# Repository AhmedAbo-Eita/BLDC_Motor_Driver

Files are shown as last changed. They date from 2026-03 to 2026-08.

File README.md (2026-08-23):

# 3-Phase BLDC & PMSM Motor Controller (ESC)







A high-performance, compact 3-phase Field-Oriented Control (FOC) Brushless DC (BLDC) and Permanent Magnet Synchronous Motor (PMSM) driver designed for robotics, e-mobility, actuators, and industrial automation.

This repository contains the complete end-to-end design stack:
* **Hardware:** Production-ready 8-layer PCB design (KiCad 10), complete multi-sheet schematics, BOM, Gerbers, assembly files, and LTspice circuit simulations.
* **Firmware:** Embedded C project for STM32G431 utilizing hardware CORDIC/FMAC acceleration, advanced motor timers, ADCs, and industrial communication stacks.
* **Control Modeling:** MATLAB/Simulink system-level simulation models for FOC algorithm development, parameter tuning, and sensorless state estimation.

---

## Hardware Preview (BLDC_MC_V1.0)

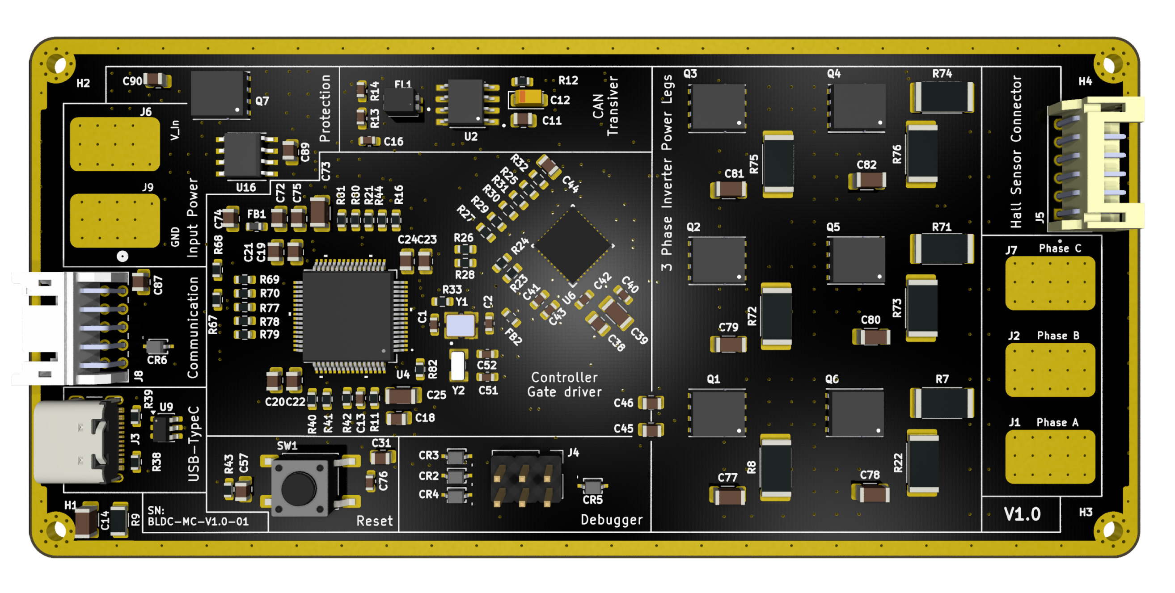
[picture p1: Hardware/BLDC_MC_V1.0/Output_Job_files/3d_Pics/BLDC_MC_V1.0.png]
BLDC_MC_V1.0 Top View


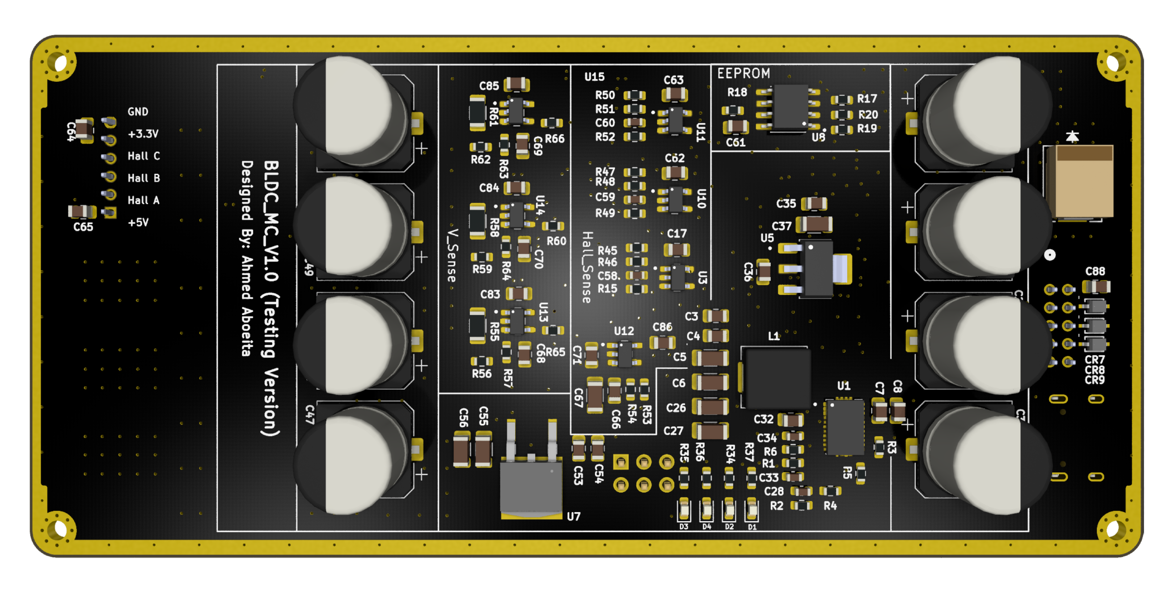
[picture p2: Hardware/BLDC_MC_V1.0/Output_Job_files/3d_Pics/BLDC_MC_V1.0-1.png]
BLDC_MC_V1.0 Bottom View


---

## Hardware V1.0 Summary & Highlight

### Key Technical Specifications

| Parameter | Specification | Details / Subsystem |
| :--- | :--- | :--- |
| **Operating Voltage ($V_{BUS}$)** | **24 V – 60 V** (60 V max) | Active reverse-polarity protection + TVS transient clamping |
| **Rated Phase Current** | **30 A continuous / peak** | Low $R_{DS(on)}$ MOSFETs + 8-layer high-copper thermal dissipation |
| **PWM Switching Frequency** | Up to **100 kHz** | Driven by STM32 advanced motor control timers |
| **Microcontroller** | **STM32G431RBT6** | 170 MHz ARM Cortex-M4, FPU, CORDIC & FMAC co-processors |
| **Gate Driver IC** | **TI DRV8353HRTAR** | Smart gate driver ($1.4\,\text{A}$ source / $700\,\text{mA}$ sink), $V_{DS}$ monitor |
| **Power Inverter Stage** | 6x **Infineon BSC027N10NS5** | 100 V, $2.7\,\text{m}\Omega$, SuperSO-8 (TDSON-8) with RC snubbers |
| **Current Sensing** | 3x **$1\,\text{m}\Omega$ Shunts** | Low-side 3-shunt sensing with shielded 4-wire Kelvin routing |
| **Voltage / BEMF Sensing** | 3-Phase Resistor Dividers | Buffered with active $+1.65\,\text{V}$ virtual ground (TLV9061) |
| **Position Feedback** | Hall Sensors + Encoders | Buffered 5 V to 3.3 V Hall inputs with RC filtering |
| **Onboard Memory** | **256 Kbit SPI EEPROM** | Microchip 25LC256 for calibration parameters & PID profiles |
| **Connectivity** | **CAN / CAN-FD, USB-C, UART, I2C** | TCAN334DR transceiver + USBLC6-2SC6 ESD protection |
| **Auxiliary Power Supplies** | **12 V / 5 V / 3.3 V** | LM74700 Ideal Diode, 12V Buck, NCV4274 (5V), LDL1117 (3.3V) |
| **PCB Form Factor** | **8-Layer High-TG180 FR4** | 2 oz outer copper, controlled impedance, 1.65 mm thickness |

---

## Repository Structure

```text
BLDC_Motor_Driver/
├── Control_Modeling/       # MATLAB & Simulink models for FOC algorithm simulation
├── Firmware/               # STM32G431 embedded C firmware (STM32CubeIDE)
└── Hardware/               # Hardware designs, simulations & manufacturing files
    ├── BLDC_MC_V1.0/       # KiCad design, schematics, BOM, Gerbers & 3D renders
    └── Simulation/         # LTspice circuit simulations
```

---

## Project Development Status

| Subsystem | Milestone | Status | Details |
| :--- | :--- | :---: | :--- |
| **Hardware (V1.0)** | Schematic & PCB Layout | **Completed** | 10 modular schematic sheets, DRC passed, 8-layer stackup |
| **Hardware (V1.0)** | Fabrication Files (Gerbers/BOM/PnP) | **Completed** | Full manufacturing package generated in [`Output_Job_files`](Hardware/BLDC_MC_V1.0/Output_Job_files/) |
| **Hardware (V1.0)** | Circuit Simulations | **Completed** | Hall sensor conditioning and active virtual-ground voltage sensor validated |
| **Firmware** | BSP & Low-level Drivers | **In Progress** | STM32G431 peripheral configuration (PWM timers, ADCs, SPI, CAN, UART) |
| **Firmware** | FOC & Commutation Algorithms | **In Progress** | Space Vector PWM (SVPWM), Park/Clarke transforms, current control loop |
| **Control Modeling** | System-Level Simulation | **In Progress** | Simulink motor and inverter models for tuning PI loops & observing dynamics |

---

## Detailed Hardware Documentation & Deliverables

For full details on the schematic sheet breakdown, connector pinouts, controlled impedance layout rules, and fabrication deliverables, refer to:
* **[Hardware V1.0 Comprehensive Documentation](Hardware/BLDC_MC_V1.0/Readme.md)**
* **[Hardware Versions & Overview](Hardware/Readme.md)**
* **[Schematic PDF](Hardware/BLDC_MC_V1.0/Output_Job_files/Board_SCH/BLDC_MC_V1.0.pdf)**
* **[Bill of Materials (BOM)](Hardware/BLDC_MC_V1.0/Output_Job_files/BOM_File/BLDC_MC_V1.0_PDF.pdf)**
* **[Fabrication Gerber Files](Hardware/BLDC_MC_V1.0/Output_Job_files/Fabrication_Files/)**

---

## Author & Project Information

* **Lead Hardware Engineer:** Ahmed Aboeita
* **Design Tools:** KiCad 10.0.5, STM32CubeIDE, MATLAB / Simulink, LTspice

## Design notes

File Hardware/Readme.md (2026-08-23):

# BLDC Motor Driver Hardware

Hardware designs for the BLDC motor driver family. Each hardware version contains complete KiCad 10 design files, schematic hierarchy, stackup definitions, circuit simulations, and production fabrication outputs.

---

## Hardware Versions

### V1.0 - 3-Phase BLDC/PMSM Motor Controller (ESC)
**Status:** **Completed & Fabrication Ready** (Rev 1.0, 2026-08-17)

BLDC_MC_V1.0 Top View

BLDC_MC_V1.0 Bottom View

A high-performance 3-phase motor controller designed for robotics, e-mobility, and industrial automation, tailored for sensored and sensorless Field-Oriented Control (FOC).

#### Technical Specifications Summary

| Specification | Value | Notes |
| :--- | :--- | :--- |
| **DC Bus Voltage** | **24 V – 60 V** (60 V max) | Bulk capacitor bank + TVS transient surge clamping |
| **Maximum Phase Current** | **30 A maximum** | Low $R_{DS(on)}$ MOSFETs + 8-layer thermal distribution |
| **PWM Switching Frequency** | Up to **100 kHz** | High-speed gate drive + STM32 advanced motor timer |
| **Main Processing Unit** | **STM32G431RBT6** | 170 MHz ARM Cortex-M4 with hardware CORDIC / FMAC |
| **Gate Driver IC** | **TI DRV8353HRTAR** | Smart Gate Drive ($1.4\,\text{A}$ source / $700\,\text{mA}$ sink) + $V_{DS}$ monitor |
| **Power Stage** | 6x **Infineon BSC027N10NS5** | 100 V, $2.7\,\text{m}\Omega$, SuperSO-8 with RC snubbers |
| **Current Sensing** | 3x **$1\,\text{m}\Omega$ Shunts** | Low-side 3-shunt sensing with Kelvin differential routing |
| **Phase Voltage Sensing** | 3-Phase Divider + Buffer | Active $+1.65\,\text{V}$ virtual ground (TLV9061) for BEMF / FOC |
| **Sensored Feedback** | 3-Channel Hall Interface | Buffered 5 V to 3.3 V with RC filtering |
| **PCB Stackup** | **8-Layer High-TG180 FR4** | 2 oz outer copper, controlled impedance (50 $\Omega$ / 100 $\Omega$) |
| **Auxiliary Rails** | **12 V, 5 V, 3.3 V** | LM74700 Ideal Diode, 12V Buck, NCV4274 (5V), LDL1117 (3.3V) |
| **Communication** | **CAN/CAN-FD, USB-C, UART, I2C** | TCAN334DR transceiver + USBLC6-2SC6 ESD protection |

#### Deliverables & Manufacturing Files

* **[Comprehensive Technical Documentation](BLDC_MC_V1.0/Readme.md)**
* **[Schematic PDF](BLDC_MC_V1.0/Output_Job_files/Board_SCH/BLDC_MC_V1.0.pdf)**
* **[Bill of Materials (BOM PDF)](BLDC_MC_V1.0/Output_Job_files/BOM_File/BLDC_MC_V1.0_PDF.pdf)** | **[BOM CSV](BLDC_MC_V1.0/Output_Job_files/BOM_File/BLDC_MC_V1.0_CSV.csv)**
* **[Fabrication Files (Gerbers & Drill)](BLDC_MC_V1.0/Output_Job_files/Fabrication_Files/)**
* **[Pick & Place Centroid Data (PnP)](BLDC_MC_V1.0/Output_Job_files/PnP_File/BLDC_MC_V1.0-all-pos.csv)**
* **[LTspice Circuit Simulations](Simulation/)**

---

## Directory Structure

```text
Hardware/
├── BLDC_MC_V1.0/               # V1.0 KiCad design files, schematics, and stackup
│   ├── Output_Job_files/       # Fabrication Gerbers, BOM, PnP, and 3D renders
│   └── Readme.md               # Detailed technical documentation & pinouts
└── Simulation/                 # LTspice circuit simulation models & testbenches
```

---

## Project Information

* **Lead Hardware Engineer:** Ahmed Aboeita
* **Design Tool:** KiCad EDA v10.0.5
* **Revision:** Rev 1.0 (Released: 2026-08-17)

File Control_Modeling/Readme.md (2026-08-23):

# BLDC & PMSM Control Modeling & Simulation

System-level simulation models and control design scripts built in MATLAB and Simulink for the BLDC motor driver family.

---

## Directory Structure

```text
Control_Modeling/
├── Functions/          # Mathematical transformations and helper functions
├── Models/             # Simulink system-level models (.slx)
│   └── BLDC_System_Level.slx # Complete 3-phase inverter, motor, and FOC loop model
├── Scripts/            # Motor parameter setup, PI gain tuning, and analysis scripts
└── Startup.m           # Startup script initializing MATLAB workspace variables
```

---

## Modeling Objectives

1. **System-Level Dynamics:** Model full electrical and mechanical dynamics of 3-phase BLDC/PMSM motors with 3-phase inverter power stage.
2. **Field-Oriented Control (FOC):** Simulate $d$-$q$ axis current control loops, speed PI controllers, and SVPWM modulation.
3. **Sensorless State Estimation:** Develop and validate sliding mode observer (SMO) and extended Kalman filter (EKF) algorithms for sensorless commutation.
4. **Parameter Extraction:** Testbed for identifying motor parameters ($R_s$, $L_d$, $L_q$, $\lambda_{pm}$, $J$, $B$).

---

## Usage

1. Open MATLAB.
2. Set the working directory to `Control_Modeling/`.
3. Run `Startup.m` to load motor parameters and control gains into the workspace.
4. Open `Models/BLDC_System_Level.slx` to simulate.

---

## Project Information

* **Lead Engineer:** Ahmed Aboeita
* **Target Hardware:** [BLDC_MC_V1.0 Hardware](../Hardware/BLDC_MC_V1.0/Readme.md)

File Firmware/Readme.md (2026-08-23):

# BLDC Motor Driver Firmware

Embedded firmware development for the BLDC motor driver family.

---

## Projects

### `BLDC_MC_V1` — STM32G431RBT6 Firmware
Firmware targeting the **BLDC_MC_V1.0** hardware board.

* **Target Microcontroller:** STM32G431RBT6 (170 MHz ARM Cortex-M4 with FPU, CORDIC & FMAC)
* **IDE / Toolchain:** STM32CubeIDE / GCC ARM Embedded
* **Configuration:** STM32CubeMX (`BLDC_MC_V1.ioc`)

### Core Firmware Architecture & Features

1. **Space Vector PWM (SVPWM):** High-frequency (up to 100 kHz) complementary PWM generation with dead-time insertion via `TIM1` advanced motor timer.
2. **Current Sensing & FOC Loop:** Synchronized ADC sampling triggered by `TIM1` center-aligned counter for accurate 3-phase current sensing and Clarke / Park transformations.
3. **CORDIC Hardware Acceleration:** Offloads trigonometric sine/cosine and vector rotation calculations from the main CPU.
4. **Position Feedback:** Support for 3-phase Hall effect sensors (via `TIM3` / input capture) and sensorless BEMF / observer modes.
5. **Communications:** CAN / CAN-FD, USB-C telemetry, and UART debugging.
6. **Hardware Protection:** Overcurrent protection, thermal throttling, undervoltage/overvoltage lockout.

---

## Project Information

* **Lead Engineer:** Ahmed Aboeita
* **Hardware Reference:** [BLDC_MC_V1.0 Hardware Documentation](../Hardware/BLDC_MC_V1.0/Readme.md)

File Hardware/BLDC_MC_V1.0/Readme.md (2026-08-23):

# 60V / 30A High-Performance BLDC & PMSM Motor Controller (ESC)








Top-side 3D render of BLDC MC V1.0

Bottom-side 3D render of BLDC MC V1.0

A compact, high-efficiency, 3-phase Field-Oriented Control (FOC) motor controller designed for high-power robotics, e-mobility, and industrial automation. Built on the **STM32G431RBT6** ARM Cortex-M4 MCU and the **TI DRV8353HRTAR** smart gate driver, this board supports high-frequency switching up to 100 kHz with extensive hardware protection, sensor feedback, and connectivity.

---

## Deliverables & Manufacturing Files

All production output packages have been generated and validated:

* **[Schematic PDF](Output_Job_files/Board_SCH/BLDC_MC_V1.0.pdf)** — Complete multi-sheet schematic with block hierarchy.
* **[Bill of Materials (BOM PDF)](Output_Job_files/BOM_File/BLDC_MC_V1.0_PDF.pdf)** | **[BOM CSV](Output_Job_files/BOM_File/BLDC_MC_V1.0_CSV.csv)** | **[BOM Excel](Output_Job_files/BOM_File/BLDC_MC_V1.0_Excel.xlsx)**
* **[Fabrication Gerber & Drill Files](Output_Job_files/Fabrication_Files/)** — RS-274X Gerbers and Excellon drill files for 8-layer PCB fabrication.
* **[Pick & Place Centroid Data](Output_Job_files/PnP_File/BLDC_MC_V1.0-all-pos.csv)** — Surface-mount component placement coordinates.
* **[Circuit Simulations](../Simulation/)** — LTspice simulation models for Hall sensor level shifting and BEMF voltage divider networks.

---

## Technical Specifications

| Parameter | Specification | Notes / Details |
| :--- | :--- | :--- |
| **Input DC Bus Voltage ($V_{BUS}$)** | **24V – 60V** (**60V Maximum**) | High-voltage bulk capacitor bank + TVS transient clamping |
| **Maximum Phase Current** | **30A Maximum** | Dependent on external heatsinking and thermal interface |
| **Maximum Switching Frequency** | Up to **100 kHz PWM** | Hardware-accelerated CORDIC/FMAC trigonometric engine |
| **Operating Temperature ($T_A$)** | **$-40^\circ\text{C}$ to $+125^\circ\text{C}$** | Designed for High-TG180 PCB substrates |
| **Main Processing Unit** | **STM32G431RBT6** (170 MHz) | ARM Cortex-M4 with FPU, 128KB Flash, 32KB SRAM |
| **Gate Driver IC** | **TI DRV8353HRTAR** | Smart Gate Drive ($1.4\text{A}$ source / $700\text{mA}$ sink) |
| **Power MOSFETs** | 6x **Infineon BSC027N10NS5** | 100V, $2.7\text{ m}\Omega$, SuperSO-8 (TDSON-8) |
| **Current Sense Shunts** | 3x **$1\text{ m}\Omega$ Metal Plate** | Low-side 3-shunt topology with Kelvin Sensing |
| **PCB Form Factor / Layers** | **8-Layer High-TG180 FR4** | 2 oz outer copper / 1 oz inner planes |

---

## Key Hardware Features

### 1. Processing & Control Core
* **STM32G431RBT6 MCU:** High-performance motor control MCU with integrated CORDIC co-processor for near-zero latency Park/Clarke transformations.
* **Dual Clock Source:** 24 MHz primary oscillator (`Y1`) for the main system PLL and 32.768 kHz crystal (`Y2`) for precise real-time timing.
* **Onboard Memory:** 256 Kbit SPI EEPROM (**25LC256-E/SN**) for non-volatile calibration parameters, PID coefficients, and motor profiles.

### 2. Inverter Power Stage & Gate Drive
* **Smart Gate Driver (DRV8353H):** Eliminates external gate resistors via software-tunable `IDRIVE` configuration. Features integrated $V_{DS}$ monitoring for cross-conduction and shoot-through protection.
* **Optimized Power Stage:** Low $R_{DS(on)}$ ($2.7\text{ m}\Omega$) 100V OptiMOS 5 MOSFETs paired with localized **1 nF + 4.7 $\Omega$ switch-node RC snubbers** to eliminate high-frequency parasitic ringing.
* **DC-Link Decoupling:** Low-ESR parallel ceramic capacitor bank ($4\times 47\,\mu\text{F} + 2\times 100\text{ nF}$) placed immediately across the inverter bridge for fast switching transient absorption.

### 3. Sensing & Signal Conditioning
* **3-Phase Low-Side Current Sensing:** $1\text{ m}\Omega$ shunts routed via strict 4-wire Kelvin differential pairs directly into the DRV8353 current sense amplifiers.
* **Phase Voltage / Sensorless BEMF Sensing:** Three buffered resistor divider networks ($100\text{ k}\Omega / 2.7\text{ k}\Omega$) with an active **+1.65V Virtual Ground buffer (TLV9061)** to allow full bidirectional phase voltage sampling across the MCU's ADC dynamic range.
* **Sensored Hall Interface:** Isolated Hall-effect inputs with hardware low-pass filtering and **TLV9061** op-amp buffers shifting 5V Hall signals safely to 3.125V/3.3V logic levels.

### 4. Auxiliary Power Architecture
* **Active Reverse Polarity Protection:** High-side Ideal Diode controller (**TI LM74700-Q1**) driving a power MOSFET to block reverse connection with zero diode forward-voltage drops.
* **Step-Down Buck Converter:** Converts high-voltage DC input down to an intermediate **+12V rail** for gate drive supplies.
* **Dual Linear Regulators (LDOs):**
  * **NCV4274 (5.0V):** Powers external Hall sensors and peripheral pull-ups.
  * **LDL1117S33R (3.3V):** Ultra-clean, low-noise supply for the STM32G4 MCU, analog references, and transceivers.

### 5. Robust Industrial Connectivity & Protection
* **CAN / CAN-FD Bus:** High-speed **TCAN334DR** transceiver with an **ACT1210** common-mode choke, split $60\Omega$ termination, and dedicated **PESD2CANFD24V-QCZ** ESD diode protection.
* **USB Type-C Interface:** USB 2.0 Type-C port with **USBLC6-2SC6** high-speed TVS diode array for diagnostics, firmware flashing, and PC telemetry.
* **Series Damping Resistors:** $33\,\Omega$ series termination resistors placed on all high-speed digital lines (PWM, SPI, SWD, UART, I2C) to ensure signal integrity and eliminate trace reflections.

---

## Schematic Sheet Architecture

The schematic is organized into 10 modular hierarchical sheets:

| Sheet ID | Sheet Name | Description & Subsystems |
| :---: | :--- | :--- |
| **01/10** | `BLDC_MC.kicad_sch` | Top-level hierarchical block interconnections and system bus mapping. |
| **02/10** | `BLDC_MC_V1.0_Power.kicad_sch` | LM74700 Ideal Diode, 12V Buck regulator, 5V/3.3V LDOs, status LEDs. |
| **03/10** | `BLDC_MC_V1.0_MCU.kicad_sch` | STM32G431RBT6, decoupling network, SWD debug port, USB-C interface. |
| **04/10** | `BLDC_MC_V1.0_Gate_Drive.kicad_sch` | DRV8353HRTAR smart gate driver, IDRIVE, VDS, and shunt amplifier tuning. |
| **05/10** | `BLDC_MC_V1.0_3Phase_Inverter_legs.kicad_sch` | 3-Phase MOSFET half-bridges, RC snubbers, $1\text{ m}\Omega$ current shunts. |
| **06/10** | `BLDC_MC_V1.0_HallSensor.kicad_sch` | 3-Channel Hall-effect sensor level-shifter and TLV9061 buffer circuitry. |
| **07/10** | `BLDC_MC_V1.0_Voltage_Sensor.kicad_sch` | 3-Phase BEMF divider network and +1.65V active virtual ground op-amp. |
| **08/10** | `BLDC_MC_V1.0_Memory.kicad_sch` | 25LC256 256Kbit SPI EEPROM and line termination resistors. |
| **09/10** | `BLDC_MC_V1.0_CAN_Transceiver.kicad_sch` | TCAN334DR CAN/CAN-FD transceiver, split termination, common-mode filter. |
| **10/10** | `BLDC_MC_V1.0_Connectors.kicad_sch` | High-current power pads, J8 comms header, J5 Hall header, TVS arrays. |

---

## Connector Pinout Definitions

### 1. Main Power & Motor Terminals (High Current)
* **`J6 / J9`:** DC Bus Input Power (`Vin_DC` [+] and `PGND` [-]).
* **`J1`:** Motor Phase A Output (`Phase_A`).
* **`J2`:** Motor Phase B Output (`Phase_B`).
* **`J7`:** Motor Phase C Output (`Phase_C`).

### 2. Communication Header (`J8` - 10-Pin S10B-PHDSS)
| Pin # | Net Name | Type | Description |
| :---: | :--- | :---: | :--- |
| **1** | `+3.3V` | Power | 3.3V Auxiliary Output Rail |
| **2** | `CAN_N` | Diff I/O | CAN Bus Dominant Low Line |
| **3** | `CAN_P` | Diff I/O | CAN Bus Dominant High Line |
| **4** | `I2C3_SCL` | Bidirectional | I2C Clock (STM32 Pin 40 / PC8) |
| **5** | `GND` | Ground | System Ground Return |
| **6** | `+5V` | Power | 5.0V Auxiliary Output Rail |
| **7** | `UART4_RX` | Input | UART4 Receive Line (STM32 Pin 53 / PC11) |
| **8** | `UART4_TX` | Output | UART4 Transmit Line (STM32 Pin 52 / PC10) |
| **9** | `I2C3_SDA` | Bidirectional | I2C Data (STM32 Pin 41 / PC9) |
| **10** | `GND` | Ground | System Ground Return |

### 3. Hall Sensor Header (`J5` - 6-Pin S6B-PH-K-S)
| Pin # | Net Name | Type | Description |
| :---: | :--- | :---: | :--- |
| **1** | `+5V` | Power | Hall Sensor Power Supply (5V) |
| **2** | `Hall_A` | Input | Phase A Hall Sensor Signal |
| **3** | `Hall_B` | Input | Phase B Hall Sensor Signal |
| **4** | `Hall_C` | Input | Phase C Hall Sensor Signal |
| **5** | `+3.3V` | Power | Optional 3.3V Pull-up / Supply |
| **6** | `GND` | Ground | Sensor Ground Return |

### 4. Debug & Programming (`J4` - 6-Pin SWD Header)
* **Pin 1:** `+3.3V` | **Pin 2:** `NRST` | **Pin 3:** `SWDIO` (PA13) | **Pin 4:** `SWCLK` (PA14) | **Pin 5:** `SWO` (PB3) | **Pin 6:** `GND`

---

## Recommended PCB Stackup & Layout Rules

### PCB Stackup

The board uses an 8-layer high-TG180 FR4 stackup with 1.65 mm nominal finished thickness. Copper thicknesses and dielectric spacing are nominal values from the fabrication stackup.

| Layer / Dielectric | Material | Thickness |
| :--- | :--- | :---: |
| L1 | Outer copper, 1 oz | 0.035 mm (1.38 mil) |
| L1-L2 | 2116 prepreg, RC54%, 4.9 mil | 0.094 mm (3.70 mil) |
| L2 | Inner copper | 0.030 mm (1.18 mil) |
| L2-L3 | FR4 core, 0.25 mm / 1 oz without copper | 0.250 mm (9.84 mil) |
| L3 | Inner copper | 0.030 mm (1.18 mil) |
| L3-L4 | 2116 prepreg, RC54%, 4.9 mil, 2 plies | 0.188 mm (7.40 mil) |
| L4 | Inner copper | 0.030 mm (1.18 mil) |
| L4-L5 | FR4 core, 0.25 mm / 1 oz without copper | 0.250 mm (9.84 mil) |
| L5 | Inner copper | 0.030 mm (1.18 mil) |
| L5-L6 | 2116 prepreg, RC54%, 4.9 mil, 2 plies | 0.188 mm (7.40 mil) |
| L6 | Inner copper | 0.030 mm (1.18 mil) |
| L6-L7 | FR4 core, 0.25 mm / 1 oz without copper | 0.250 mm (9.84 mil) |
| L7 | Inner copper | 0.030 mm (1.18 mil) |
| L7-L8 | 2116 prepreg, RC54%, 4.9 mil | 0.094 mm (3.70 mil) |
| L8 | Outer copper, 1 oz | 0.035 mm (1.38 mil) |

### Controlled Impedance

| Target impedance | Type | Signal layer | Reference layer | Trace width | Differential spacing |
| :---: | :--- | :---: | :---: | :---: | :---: |
| 50 ohm | Single-ended, non-coplanar | L1 | L2 | 6.790 mil (0.172 mm) | - |
| 50 ohm | Single-ended, non-coplanar | L3 | L2 / L4 | 8.370 mil (0.213 mm) | - |
| 100 ohm | Differential pair, non-coplanar | L1 | L2 | 5.270 mil (0.134 mm) | 8.000 mil (0.203 mm) |

* **Power Decoupling:** Place low-ESR ceramic caps ($47\,\mu\text{F}$) as close as physically possible to the high-side MOSFET drains and low-side source shunts.
* **Kelvin Current Sensing:** Keep `SA+`/`SA-`, `SB+`/`SB-`, and `SC+`/`SC-` routed strictly as shielded differential pairs on Layer 3, isolated from high $dv/dt$ switch-node planes.

---

## Author & Project Information
* **Lead Hardware Engineer:** Ahmed Aboeita
* **Design Suite:** KiCad E.D.A. v10.0.5
* **Design Revision:** Rev 1.0 (2026-08-17)

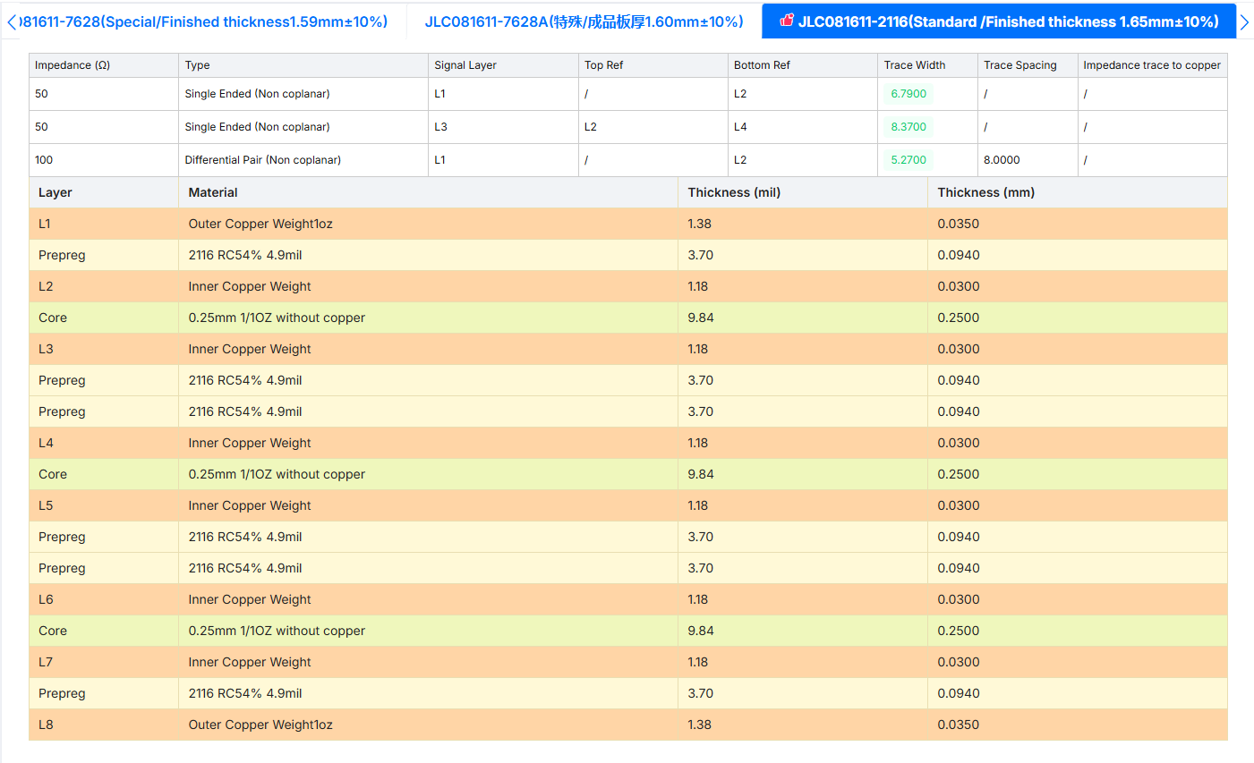
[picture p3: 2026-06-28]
Hardware/BLDC_MC_V1.0/Stackup/JLC-8Layers.png

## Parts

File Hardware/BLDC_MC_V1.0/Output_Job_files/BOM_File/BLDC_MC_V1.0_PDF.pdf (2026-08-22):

MP | Qty | Reference | Value | Assembled | LCSC_PN | Description | Footprint
CC0603JRNPO9BN300 | 2 | C1,C2 | 30pF | Yes | C113797 | Unpolarized capacitor | Capacitor_SMD:C_0603_1608Metric
CL21B104KCFNNNE | 42 | C3,C4,C7,C8,C11,C17,C18,C 19,C20,C21,C22,C23,C24,C3 1,C35,C38,C44,C45,C46,C54, C57,C61,C62,C63,C64,C65,C 66,C68,C69,C70,C71,C72,C7 4,C75,C83,C84,C85,C86,C87, C88,C89,C90 | 100nF | No,Yes | C28233 | Unpolarized capacitor | Capacitor_SMD:C_0805_2012Metric
GRM31CR61E476ME44L | 5 | C5,C6,C26,C27,C39 | 47uF | Yes | C403725 | Unpolarized capacitor | Capacitor_SMD:C_1206_3216Metric
118EC449 | 8 | C9,C10,C29,C30,C47,C48,C4 9,C50 | 47uF | Yes | C46528101 | Polarized capacitor | Capacitor_SMD:CP_Elec_10x10.5
TAJA106K016RNJ | 1 | C12 | 10uF | Yes | C7171 | Polarized capacitor | Capacitor_Tantalum_SMD:CP_EIA-3216-18_Kemet-A
CL10C100JB8NNNC | 3 | C13,C16,C28 | 10pF | No | C1634 | Unpolarized capacitor | Capacitor_SMD:C_0603_1608Metric
CL31B475KBHNNNE | 6 | C25,C37,C55,C56,C67,C73 | 4.7uF | Yes | C51205 | Unpolarized capacitor | Capacitor_SMD:C_1206_3216Metric
CL21B474KBFNNNE | 1 | C32 | 470nF | Yes | C13967 | Unpolarized capacitor | Capacitor_SMD:C_0805_2012Metric
CC0603KRX7R9BB103 | 1 | C33 | 10nF | Yes | C100042 | Unpolarized capacitor | Capacitor_SMD:C_0603_1608Metric
GRM188Z71E225KE43D | 1 | C34 | 2.2uF | Yes | C415535 | Unpolarized capacitor | Capacitor_SMD:C_0603_1608Metric
CL21B105KBFNNNE | 2 | C36,C53 | 1uF | Yes | C28323 | Unpolarized capacitor | Capacitor_SMD:C_0805_2012Metric
CL10B105KA8NNNC | 4 | C40,C41,C43,C76 | 1uF | Yes | C29936 | Unpolarized capacitor | Capacitor_SMD:C_0603_1608Metric
CL10B473KB8NNNC | 1 | C42 | 47nF | | C1622 | Unpolarized capacitor | Capacitor_SMD:C_0603_1608Metric
CL10C200JB8NNNC | 2 | C51,C52 | 20pF | Yes | C1648 | Unpolarized capacitor | Capacitor_SMD:C_0603_1608Metric
CC1206KKX7RDBB102 | 6 | C77,C78,C79,C80,C81,C82 | 1nF | No | C23631 | Unpolarized capacitor | Capacitor_SMD:C_1206_3216Metric
PESD2CANFD24V-QCZ | 1 | CR1 | PESD2CANFD24V-QCZ | Yes | C6251381 | 42VC Clamp 2.6A@8/20us Ipp ESD DIODE DFN1412D-3 | BLDC_Motor_Driver_Components_Footprint:DFN1412D-3_SOT8009_NEX
PESD3V3L1BAZ | 8 | CR2,CR3,CR4,CR5,CR6,CR7,C R8,CR9 | PESD3V3L1BA_115 | Yes | C552513 | 26VC Clamp ESD DIODE SOD-323 | BLDC_Motor_Driver_Components_Footprint:DIODE_PESD3V3L1BA_115_NEX
SMDJ110CA | 1 | CR10 | SMDJ110CA | | C2990268 | 177VC Clamp 16.9A Ipp TVS DIODE SMC(DO-214AB) | BLDC_Motor_Driver_Components_Footprint:SMDJSeries_LTF
YLED0603R | 4 | D1,D2,D3,D4 | LED | Yes | C19171390 | Light emitting diode | LED_SMD:LED_0603_1608Metric
BLM18AG601SN1D | 2 | FB1,FB2 | FerriteBead | Yes | C19330 | Ferrite bead | Inductor_SMD:L_0603_1608Metric
ACT1210-510-2P-TL00 | 1 | FL1 | ACT1210-510-2P-TL00 | Yes | C95572 | | BLDC_Motor_Driver_Components_Footprint:FIL_ACT1210-510-2P-TL00
TYPE-C 16PIN 2MD(073) | 1 | J3 | USB_C_Receptacle_US B2.0_16P | Yes | C2765186 | USB 2.0-only 16P Type-C Receptacle connector | BLDC_Motor_Driver_Components_Footprint:USB_C_Receptacle_GCT_USB4105-xx-A_16P_TopMnt_Horizontal
S6B-PH-K-S(LF)(SN) | 1 | J5 | S6B-PH-K-S_LF__SN_ | Yes | C157920 | Connector Header Through Hole, Right Angle 6 position 0.079 (2.00mm) | BLDC_Motor_Driver_Components_Footprint:JST_S6B-PH-K-S_LF__SN_
S10B-PHDSS(LF)(SN) | 1 | J8 | S10B-PHDSS LFSN | Yes | C161672 | CONN HEADER TH R/A 10POS 2mm | BLDC_Motor_Driver_Components_Footprint:CONN_S10B-PHDSS_JST
SMMS0650-100M | 1 | L1 | 10uH | Yes | C149584 | Inductor | Inductor_SMD:L_KOHERelec_MDA7030
BSC027N10NS5ATMA1 | 7 | Q1,Q2,Q3,Q4,Q5,Q6,Q7 | BSC027N10NS5ATMA1 | | C534315 | N-Channel 100V 3W Surface Mount TDSON-8-EP(5x6) | BLDC_Motor_Driver_Components_Footprint:PG-TSON-8-3_INF
RT0603BRD07100KL | 2 | R1,R2 | 100K | Yes | C122538 | Resistor | Resistor_SMD:R_0603_1608Metric
FRC0603F0000TS | 10 | R3,R6,R23,R24,R25,R26,R28,R 29,R31,R33 | 0R | No,Yes | C2906974 | Resistor | Resistor_SMD:R_0603_1608Metric
CRCW06039K09FKEA | 1 | R4 | 9.09K | Yes | C844591 | Resistor | Resistor_SMD:R_0603_1608Metric
RC0603FR-0710KL,RT0603BRD0710KL | 15 | R5,R15,R17,R18,R19,R32,R34, R37,R43,R49,R52,R53,R54,R6 7,R68 | 10k | No,Yes | C95204,C98220 | Resistor | Resistor_SMD:R_0603_1608Metric
FPM253WJR001TML | 3 | R7,R71,R74 | 1mR | Yes | C7419999 | Resistor | Resistor_SMD:R_2512_6332Metric
25121WJ047JT4E | 6 | R8,R22,R72,R73,R75,R76 | 4R7 | No | C25489 | Resistor | Resistor_SMD:R_2512_6332Metric_Pad1.40x3.35mm_HandSolder
RC0603FR-0733RL | 23 | R11,R12,R16,R20,R21,R40,R4 1,R42,R44,R57,R60,R63,R64,R 65,R66,R69,R70,R77,R78,R79, R80,R81,R82 | 33R | Yes | C108661 | Resistor | Resistor_SMD:R_0603_1608Metric
RTT0360R0FTP | 2 | R13,R14 | 60R | Yes | C166918 | Resistor | Capacitor_SMD:C_0603_1608Metric
RT0603BRD0718KL | 5 | R27,R30,R45,R47,R50 | 18K | Yes | C309650 | Resistor | Resistor_SMD:R_0603_1608Metric
0603WAF3301T5E | 2 | R35,R36 | 3k3 | Yes | C22978 | Resistor | Resistor_SMD:R_0603_1608Metric
0603WAF5101T5E | 2 | R38,R39 | 5k1 | Yes | C23186 | Resistor | Resistor_SMD:R_0603_1608Metric
RT0603BRD0730KL | 3 | R46,R48,R51 | 30K | Yes | C723585 | Resistor | Resistor_SMD:R_0603_1608Metric
FRC1206F1003TS | 3 | R55,R58,R61 | 100K | Yes | C2907368 | Resistor | Resistor_SMD:R_1206_3216Metric
RT0603BRD072K7L | 3 | R56,R59,R62 | 2k7 | Yes | C705760 | Resistor | Resistor_SMD:R_0603_1608Metric
TL3301NF160QG | 1 | SW1 | SW_Push | Yes | C273526 | Push button switch, generic, two pins | Button_Switch_SMD:SW_Push_1P1T_NO_E-Switch_TL3301NxxxxxG

LM76005RNPR | 1 | U1 | LM76005RNPR | Yes | C2866241 | 3.5-V to 60-V, 5-A synchronous step-down voltage converter | BLDC_Motor_Driver_Components_Footprint:QFN50P600X400X80-31N
TCAN334DR | 1 | U2 | TCAN334DR | | C2871143 | 3.3V CAN transceiver with CANFD (Flexible Data) Rate) | BLDC_Motor_Driver_Components_Footprint:SOIC127P599X175-8N
TLV9061IDBVR | 7 | U3,U10,U11,U12,U13,U14,U1 5 | TLV9061IDBVR | Yes | C398358 | 1.6mV Rail-to-Rail Input, Rail-to-Rail Output 0.5pA 103dB 538uA 10MHz 1 SOT-23-5 Amplifiers RoHS | BLDC_Motor_Driver_Components_Footprint:SOT95P280X145-5N
STM32G431RBT6 | 1 | U4 | STM32G431RBT6 | Yes | C431633 | Arm Cortex-M4 32b MCU+FPU,170MHz / 213DMIPS, up to 128 KB Flash, 32KB SRAM, rich analog, math accelerator | BLDC_Motor_Driver_Components_Footprint:LQFP64-10x10mm
LDL1117S33R | 1 | U5 | LDL1117S33R | Yes | C435835 | 3.3V 18V Positive Fixed SOT-223-4 Voltage Regulators - Linear, Low Drop Out (LDO) Regulators RoHS | BLDC_Motor_Driver_Components_Footprint:SOT230P700X180-4N
DRV8353HRTAR | 1 | U6 | DRV8353HRTAR | Yes | C2150766 | Three Phase MOSFET 700mA 700mA WQFN-40-EP(6x6) Motor Drivers, Controllers RoHS | BLDC_Motor_Driver_Components_Footprint:RTA0040B
NCV4274ADT50RKG | 1 | U7 | NCV4274ADT50RKG | Yes | C233416 | 5V 40V Positive Fixed TO-252-2(DPAK) Voltage Regulators - Linear, Low Drop Out (LDO) Regulators RoHS | BLDC_Motor_Driver_Components_Footprint:DPAK-3_ONS
25LC256-E/SN | 1 | U8 | 25LC256-E_SN | Yes | C1349834 | 2.5V~5.5V 256Kbit 10MHz SPI SOIC-8 Memory (ICs) RoHS | BLDC_Motor_Driver_Components_Footprint:SOIC127P599X175-8N
USBLC6-2SC6 | 1 | U9 | USBLC6-2SC6 | Yes | | Very low capacitance ESD protection diode, 2 data-line, SOT-23-6 | Package_TO_SOT_SMD:SOT-23-6
LM74700QDRQ1 | 1 | U16 | LM74700QDRQ1 | Yes | C33579657 | 20mV 11mA 65V 2.37A SOIC-8 OR Controllers, Ideal Diodes RoHS | BLDC_Motor_Driver_Components_Footprint:SOIC8_D_TEX
7M-24.000MAAJ-T | 1 | Y1 | 7M-24.000MAAJ-T | Yes | C2450233 | Crystal 24MHz Â±30ppm 18pF 60Î© SMD3225-4P | BLDC_Motor_Driver_Components_Footprint:XTAL_7M-24.000MAAJ-T
ABS07-32.768KHZ-T | 1 | Y2 | ABS07-32.768KHZ-T | Yes | C130253 | Crystal 32.768kHz Â±20ppm 12.5pF 70kÎ© SMD3215-2P | BLDC_Motor_Driver_Components_Footprint:XTAL_ABS07-32.768KHZ-T
FRC1206J105 TS | 1 | R9 | 1M | Yes | C2907441 | Resistor | Resistor_SMD:R_1206_3216Metric
TCC1206X7R103K101DT | 1 | C14 | 10nF | Yes | C377055 | Unpolarized capacitor | Capacitor_SMD:C_1206_3216Metric

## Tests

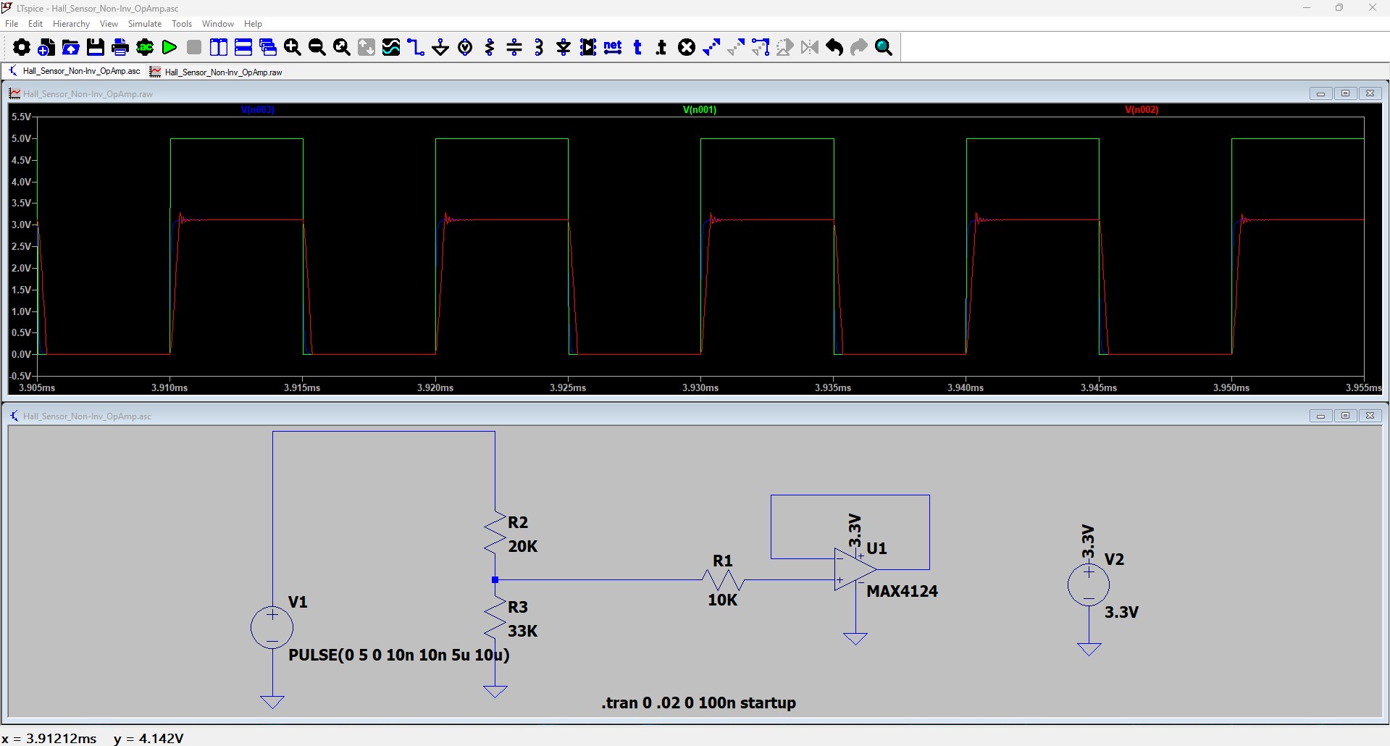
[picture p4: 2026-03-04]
Hardware/Simulation/Hall_Sensor_Circuit/Results.jpg

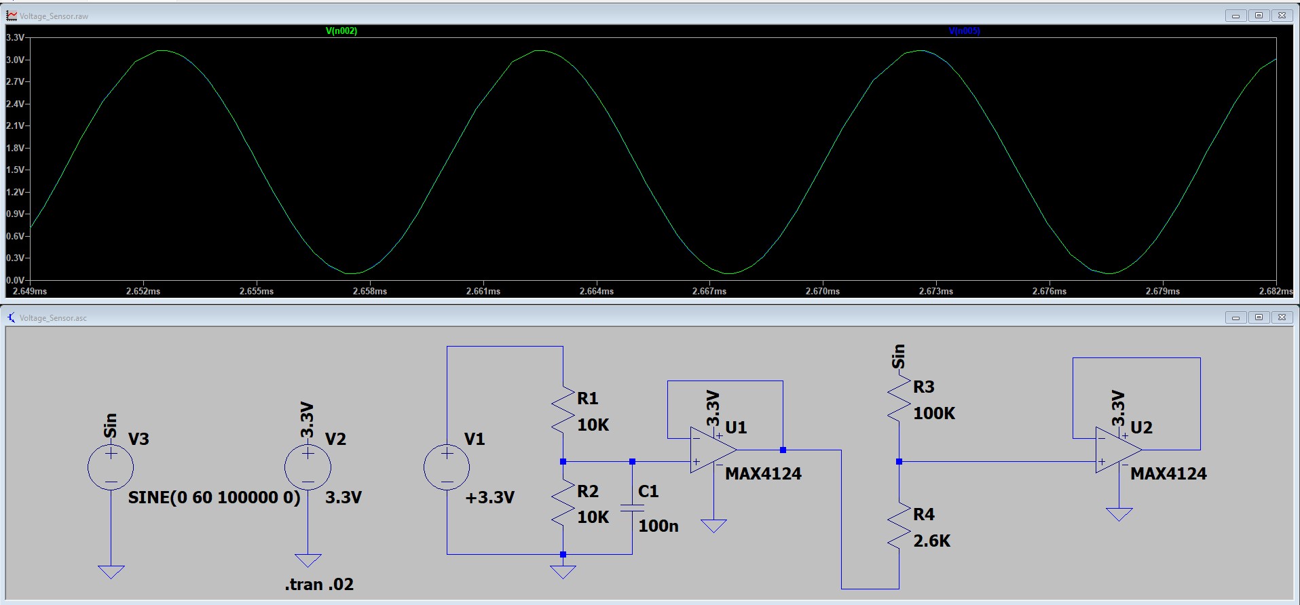
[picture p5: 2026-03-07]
Hardware/Simulation/Voltage_Sensor/Results.jpg

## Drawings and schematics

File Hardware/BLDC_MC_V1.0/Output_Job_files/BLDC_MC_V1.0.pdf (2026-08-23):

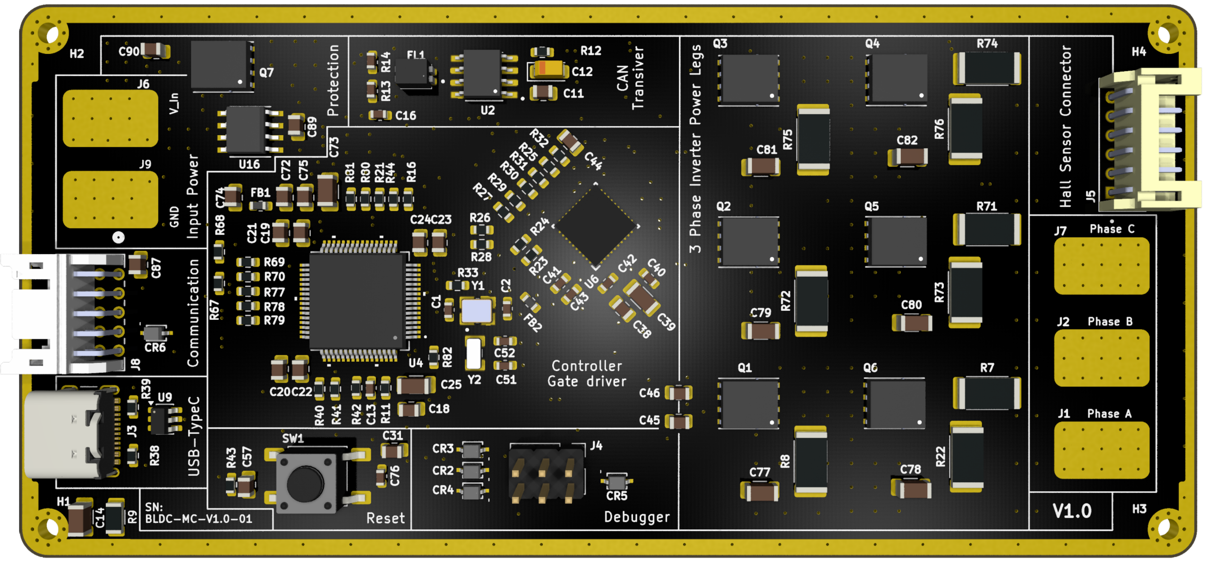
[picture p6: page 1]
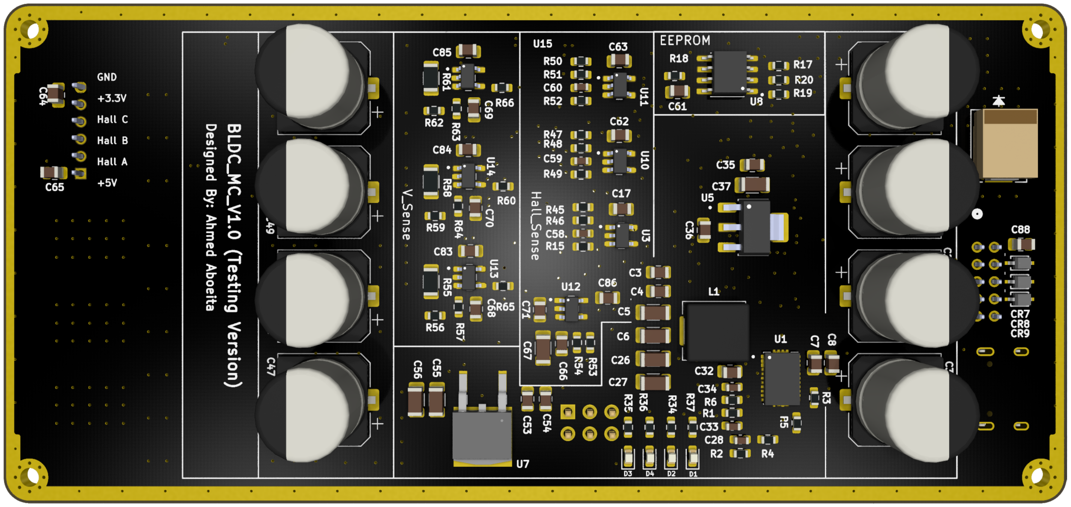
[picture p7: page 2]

# GLA SA+

# GD_Enable PWM_A_L PWM_C_L PWM_C_H

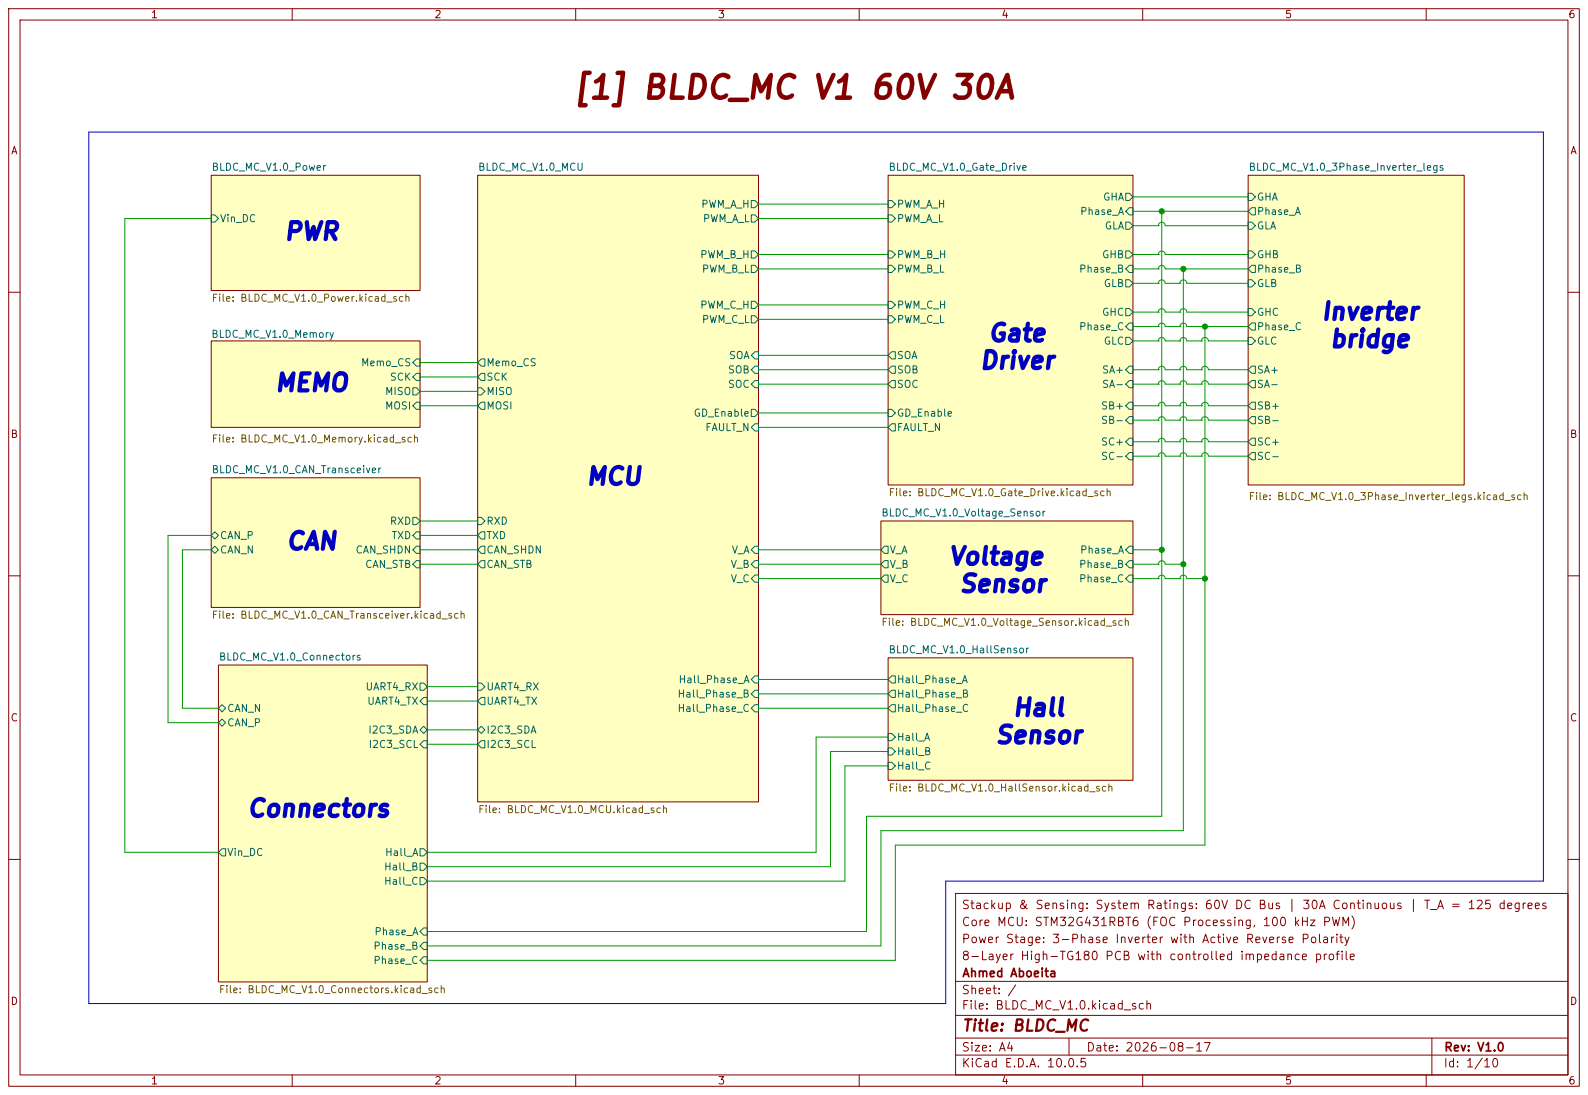
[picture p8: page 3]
D Date: 2026-08-17; KiCad E.D.A. 10.0.5; Size: A4; Rev: V1.0; Phase_C; Phase_A Phase_B; GLB; GHC; GLC; GHB; GHA BLDC_MC_V1.0_3Phase_Inverter_legs File: BLDC_MC_V1.0_3Phase_Inverter_legs.kicad_sch; Vin_DC; BLDC_MC_V1.0_Power File: BLDC_MC_V1.0_Power.kicad_sch; Phase_A; Phase_B; BLDC_MC_V1.0_Voltage_Sensor File: BLDC_MC_V1.0_Voltage_Sensor.kicad_sch; TXD; RXD; SOA SOB; FAULT_N; PWM_A_H; PWM_B_H PWM_B_L Hall_Phase_A Hall_Phase_C Hall_Phase_B; V_A CAN_STB; CAN_SHDN; UART4_RX I2C3_SCL UART4_TX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

GHA GLA Phase_A GHC

BLDC_MC_V1.0_CAN_Transceiver File: BLDC_MC_V1.0_CAN_Transceiver.kicad_sch MOSI SCK Memo_CS MISO

SOC SCK MISO MOSI Memo_CS

Stackup & Sensing: System Ratings: 60V DC Bus | 30A Continuous | T_A = 125 degrees
Core MCU: STM32G431RBT6 (FOC Processing, 100 kHz PWM)
Power Stage: 3-Phase Inverter with Active Reverse Polarity
8-Layer High-TG180 PCB with controlled impedance profile
Ahmed Aboeita
Sheet: /
File: BLDC_MC_V1.0.kicad_sch
Title: BLDC_MC

VCC_Buck | Voltage Level | Usage

# Buck IC Circuit

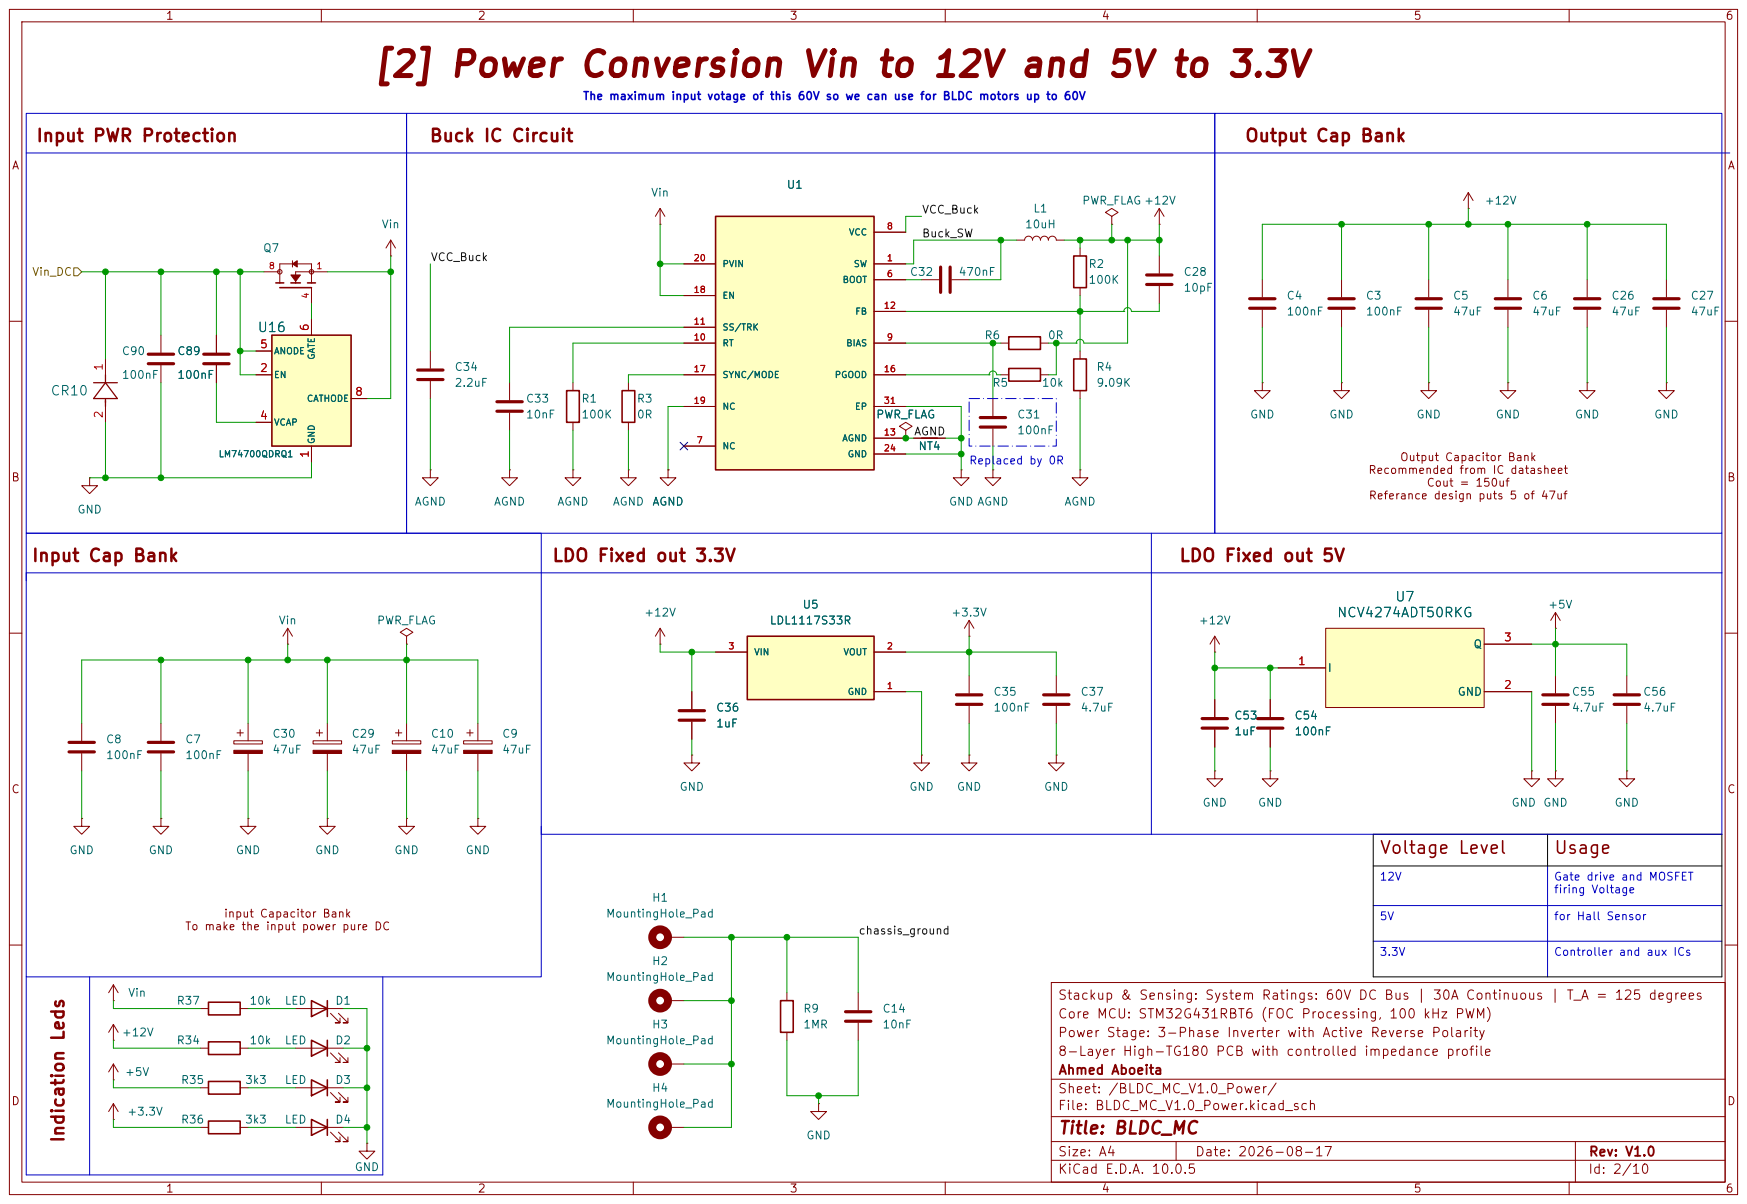
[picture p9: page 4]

Replaced by 0R [2] Power Conversion Vin to 12V and 5V to 3.3V
Input PWR Protection Indication Leds

The maximum input votage of this 60V so we can use for BLDC motors up to 60V

Output Capacitor Bank Recommended from IC datasheet Cout = 150uf Referance design puts 5 of 47uf LDO Fixed out 5V

12V | Gate drive and MOSFET
firing Voltage 5V for Hall Sensor 3.3V Controller and aux ICs

Stackup & Sensing: System Ratings: 60V DC Bus | 30A Continuous | T_A = 125 degrees
Core MCU: STM32G431RBT6 (FOC Processing, 100 kHz PWM)
Power Stage: 3-Phase Inverter with Active Reverse Polarity
8-Layer High-TG180 PCB with controlled impedance profile
Ahmed Aboeita
Sheet: /BLDC_MC_V1.0_Power/
File: BLDC_MC_V1.0_Power.kicad_sch
Title: BLDC_MC

# 100nF R38

# [3] STM32G431RBT6 Controller Interface

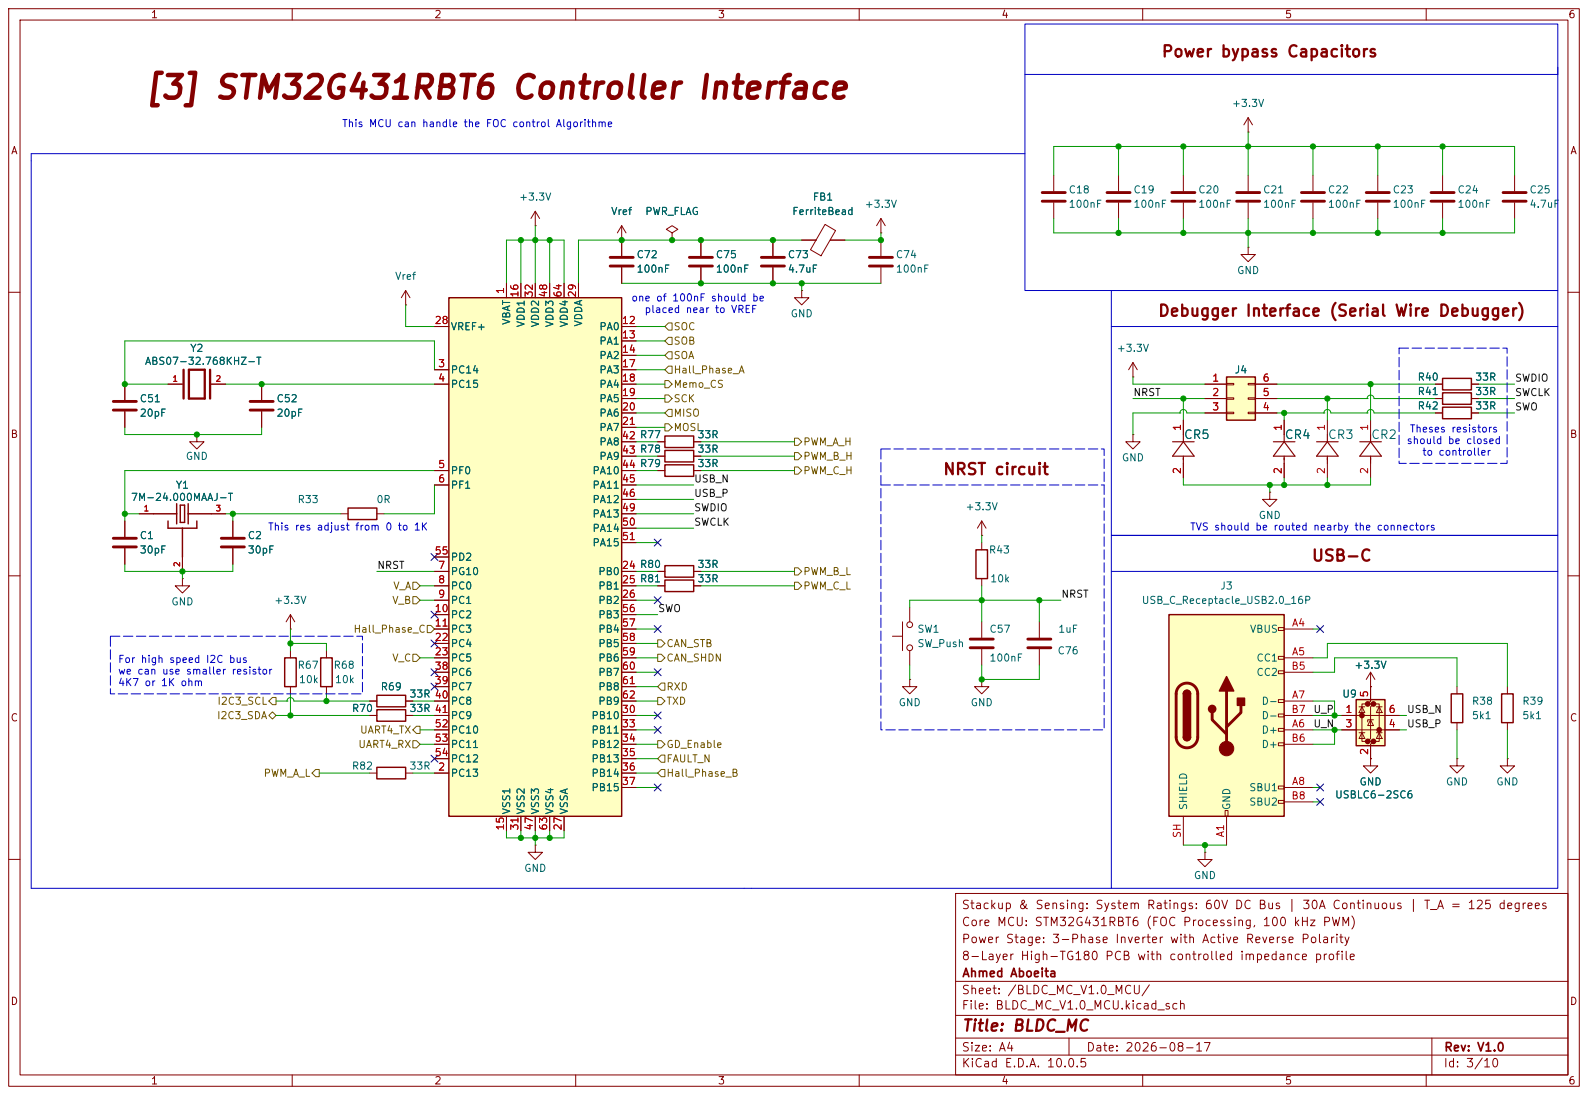
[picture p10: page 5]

This MCU can handle the FOC control Algorithme

Debugger Interface (Serial Wire Debugger)

Theses resistors should be closed

This res adjust from 0 to 1K

Stackup & Sensing: System Ratings: 60V DC Bus | 30A Continuous | T_A = 125 degrees
Core MCU: STM32G431RBT6 (FOC Processing, 100 kHz PWM)
Power Stage: 3-Phase Inverter with Active Reverse Polarity
8-Layer High-TG180 PCB with controlled impedance profile
Ahmed Aboeita
Sheet: /BLDC_MC_V1.0_MCU/
File: BLDC_MC_V1.0_MCU.kicad_sch
Title: BLDC_MC

# VDS 29 GAIN 30 DVDD 38 U6

# [4] Smart Gate Drive

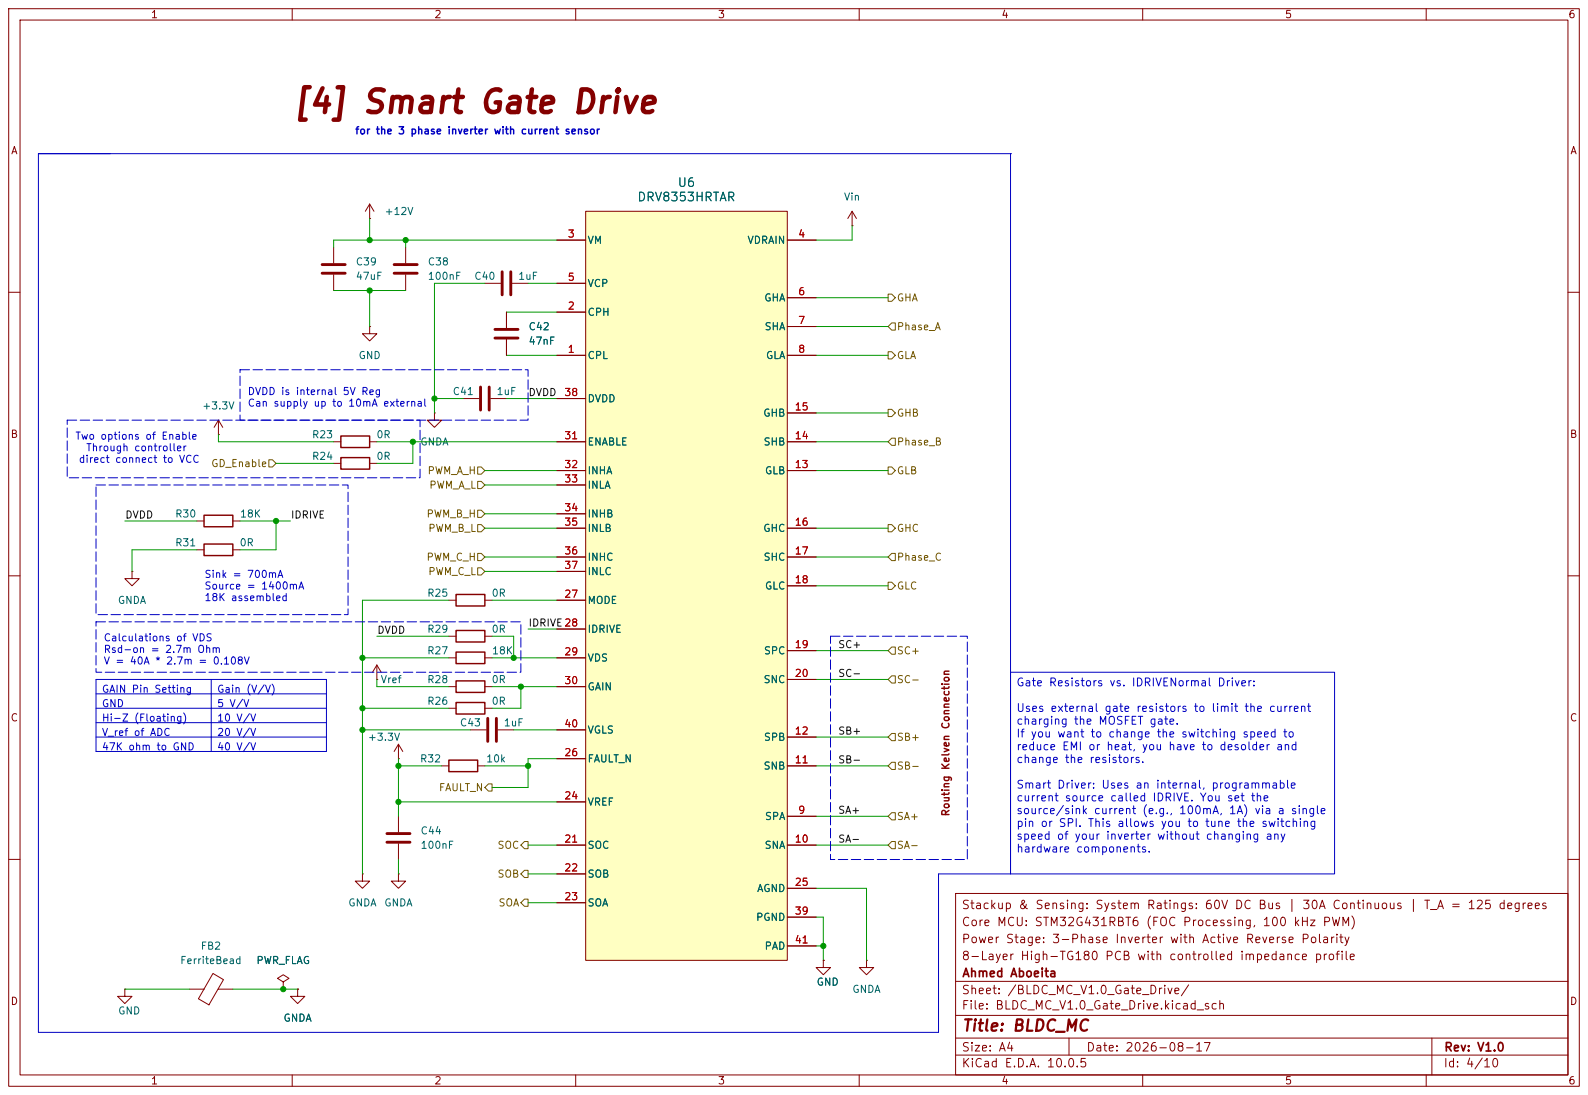
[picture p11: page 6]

for the 3 phase inverter with current sensor Sink = 700mA Source = 1400mA 18K assembled DVDD is internal 5V Reg Can supply up to 10mA external Calculations of VDS Rsd-on = 2.7m Ohm V = 40A * 2.7m = 0.108V

Two options of Enable
Through controller direct connect to VCC

speed of your inverter without changing any hardware components. Routing Kelven Connection

If you want to change the switching speed to
reduce EMI or heat, you have to desolder and
change the resistors. Smart Driver: Uses an internal, programmable

current source called IDRIVE. You set the
source/sink current (e.g., 100mA, 1A) via a single
pin or SPI. This allows you to tune the switching

Core MCU: STM32G431RBT6 (FOC Processing, 100 kHz PWM)
Power Stage: 3-Phase Inverter with Active Reverse Polarity
8-Layer High-TG180 PCB with controlled impedance profile
Ahmed Aboeita
Sheet: /BLDC_MC_V1.0_Gate_Drive/
File: BLDC_MC_V1.0_Gate_Drive.kicad_sch
Title: BLDC_MC

# DC Link

# [5] 3 Phases Inverter Bridge

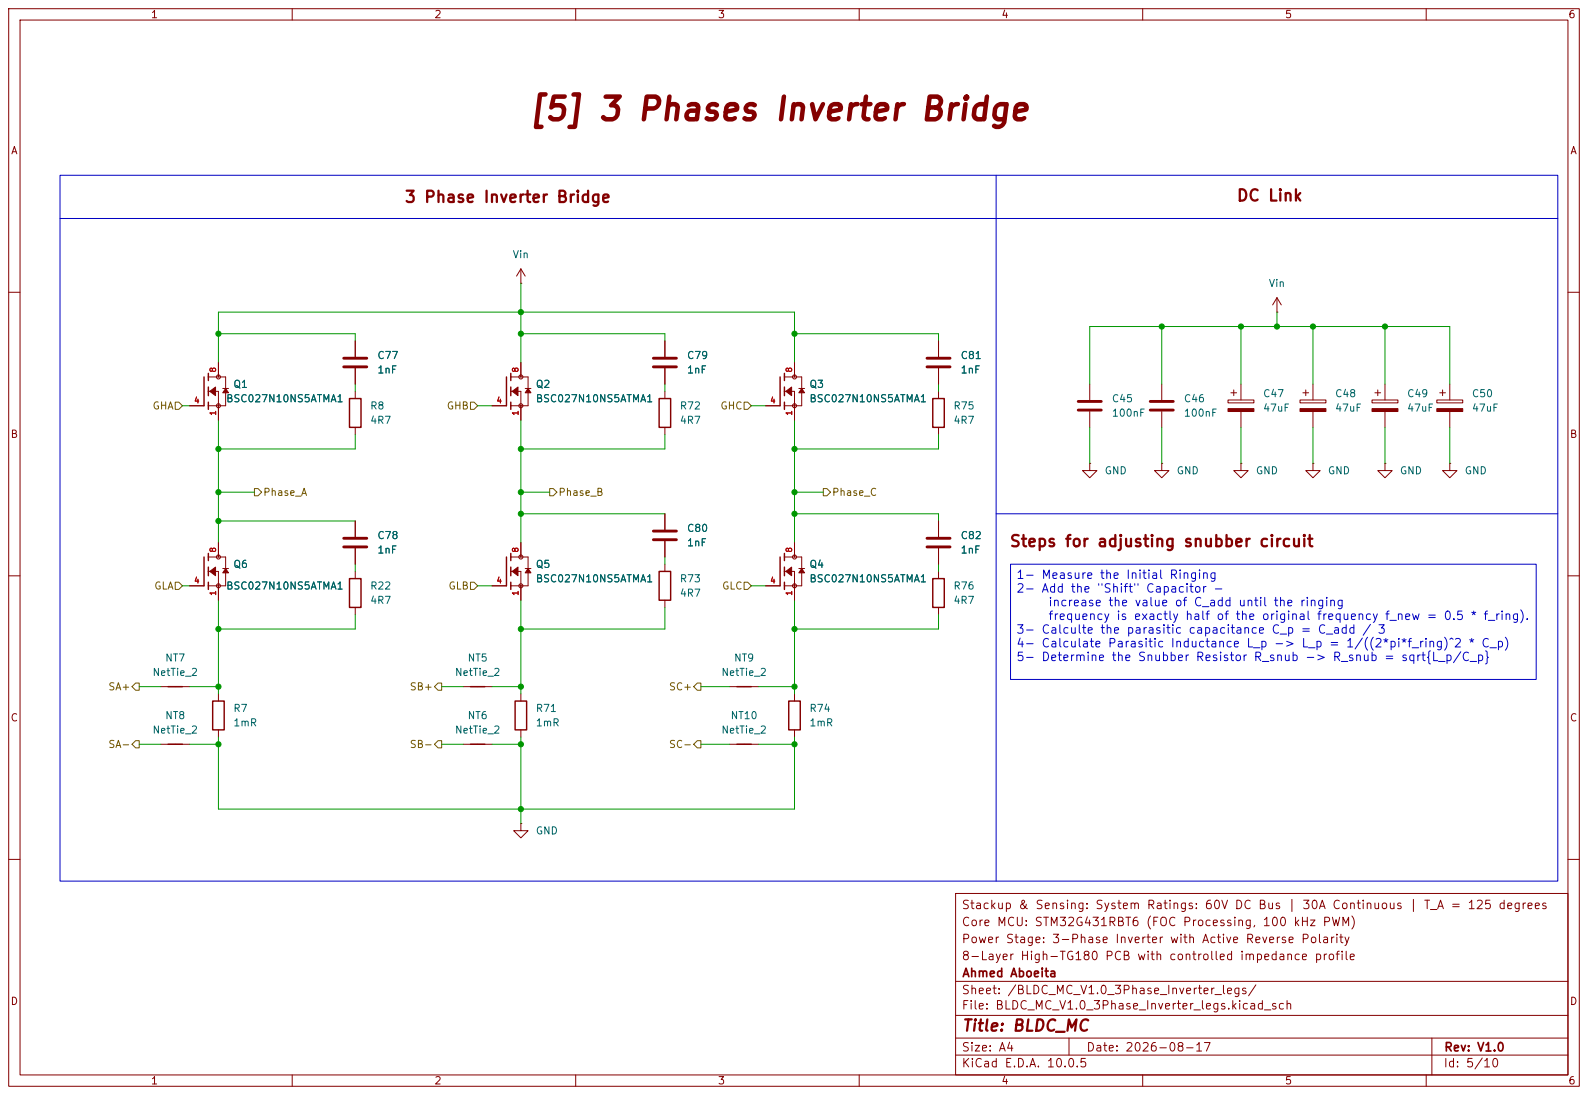
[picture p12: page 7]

Steps for adjusting snubber circuit

2- Add the "Shift" Capacitor -

increase the value of C_add until the ringing
frequency is exactly half of the original frequency f_new = 0.5 * f_ring).

3- Calculte the parasitic capacitance C_p = C_add / 3
4- Calculate Parasitic Inductance L_p -> L_p = 1/((2*pi*f_ring)^2 * C_p)
5- Determine the Snubber Resistor R_snub -> R_snub = sqrt{L_p/C_p}

Stackup & Sensing: System Ratings: 60V DC Bus | 30A Continuous | T_A = 125 degrees
Core MCU: STM32G431RBT6 (FOC Processing, 100 kHz PWM)
Power Stage: 3-Phase Inverter with Active Reverse Polarity
8-Layer High-TG180 PCB with controlled impedance profile
Ahmed Aboeita
Sheet: /BLDC_MC_V1.0_3Phase_Inverter_legs/
File: BLDC_MC_V1.0_3Phase_Inverter_legs.kicad_sch
Title: BLDC_MC
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

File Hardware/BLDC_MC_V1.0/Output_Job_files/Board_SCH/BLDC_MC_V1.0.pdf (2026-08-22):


BLDC_MC_V1.0_CAN_Transceiver File: BLDC_MC_V1.0_CAN_Transceiver.kicad_sch MOSI SCK Memo_CS MISO

SOC SCK MISO MOSI Memo_CS

Stackup & Sensing: System Ratings: 60V DC Bus | 30A Continuous | T_A = 125 degrees
Core MCU: STM32G431RBT6 (FOC Processing, 100 kHz PWM)
Power Stage: 3-Phase Inverter with Active Reverse Polarity
8-Layer High-TG180 PCB with controlled impedance profile
Ahmed Aboeita
Sheet: /
File: BLDC_MC_V1.0.kicad_sch
Title: BLDC_MC

Size: A4 | Rev: V1.0
KiCad E.D.A. 10.0.5 | Id: 1/10


Replaced by 0R [2] Power Conversion Vin to 12V and 5V to 3.3V
Input PWR Protection Indication Leds

The maximum input votage of this 60V so we can use for BLDC motors up to 60V

Buck IC Circuit | Output Cap Bank

Vin | | PWR_FLAG +12V L1

AGND Input Cap Bank | LDL1117S33R NT4 C30 +3.3V GND AGND | 4.7uF GND +5V R3

GND Output Capacitor Bank Recommended from IC datasheet Cout = 150uf Referance design puts 5 of 47uf LDO Fixed out 5V | GND | GND

Vin PWR_FLAG | AGND | +12V C53

input Capacitor Bank | 47uF GND | | 1uF +12V 47uF C8

12V | Gate drive and MOSFET
firing Voltage 5V for Hall Sensor 3.3V Controller and aux ICs

Stackup & Sensing: System Ratings: 60V DC Bus | 30A Continuous | T_A = 125 degrees
Core MCU: STM32G431RBT6 (FOC Processing, 100 kHz PWM)
Power Stage: 3-Phase Inverter with Active Reverse Polarity
8-Layer High-TG180 PCB with controlled impedance profile
Ahmed Aboeita
Sheet: /BLDC_MC_V1.0_Power/
File: BLDC_MC_V1.0_Power.kicad_sch
Title: BLDC_MC


This MCU can handle the FOC control Algorithme

Debugger Interface (Serial Wire Debugger)

Theses resistors should be closed

This res adjust from 0 to 1K

Stackup & Sensing: System Ratings: 60V DC Bus | 30A Continuous | T_A = 125 degrees
Core MCU: STM32G431RBT6 (FOC Processing, 100 kHz PWM)
Power Stage: 3-Phase Inverter with Active Reverse Polarity
8-Layer High-TG180 PCB with controlled impedance profile
Ahmed Aboeita
Sheet: /BLDC_MC_V1.0_MCU/
File: BLDC_MC_V1.0_MCU.kicad_sch
Title: BLDC_MC


for the 3 phase inverter with current sensor Sink = 700mA Source = 1400mA 18K assembled DVDD is internal 5V Reg Can supply up to 10mA external Calculations of VDS Rsd-on = 2.7m Ohm V = 40A * 2.7m = 0.108V
FerriteBead +3.3V GND

Two options of Enable
Through controller direct connect to VCC

speed of your inverter without changing any hardware components. Routing Kelven Connection

If you want to change the switching speed to
reduce EMI or heat, you have to desolder and
change the resistors. Smart Driver: Uses an internal, programmable

current source called IDRIVE. You set the
source/sink current (e.g., 100mA, 1A) via a single
pin or SPI. This allows you to tune the switching

Core MCU: STM32G431RBT6 (FOC Processing, 100 kHz PWM)
Power Stage: 3-Phase Inverter with Active Reverse Polarity
8-Layer High-TG180 PCB with controlled impedance profile
Ahmed Aboeita
Sheet: /BLDC_MC_V1.0_Gate_Drive/
File: BLDC_MC_V1.0_Gate_Drive.kicad_sch
Title: BLDC_MC


3 Phase Inverter Bridge | DC Link

Vin

Steps for adjusting snubber circuit

2- Add the "Shift" Capacitor -

increase the value of C_add until the ringing
frequency is exactly half of the original frequency f_new = 0.5 * f_ring).

3- Calculte the parasitic capacitance C_p = C_add / 3
4- Calculate Parasitic Inductance L_p -> L_p = 1/((2*pi*f_ring)^2 * C_p)
5- Determine the Snubber Resistor R_snub -> R_snub = sqrt{L_p/C_p}

Stackup & Sensing: System Ratings: 60V DC Bus | 30A Continuous | T_A = 125 degrees
Core MCU: STM32G431RBT6 (FOC Processing, 100 kHz PWM)
Power Stage: 3-Phase Inverter with Active Reverse Polarity
8-Layer High-TG180 PCB with controlled impedance profile
Ahmed Aboeita
Sheet: /BLDC_MC_V1.0_3Phase_Inverter_legs/
File: BLDC_MC_V1.0_3Phase_Inverter_legs.kicad_sch
Title: BLDC_MC

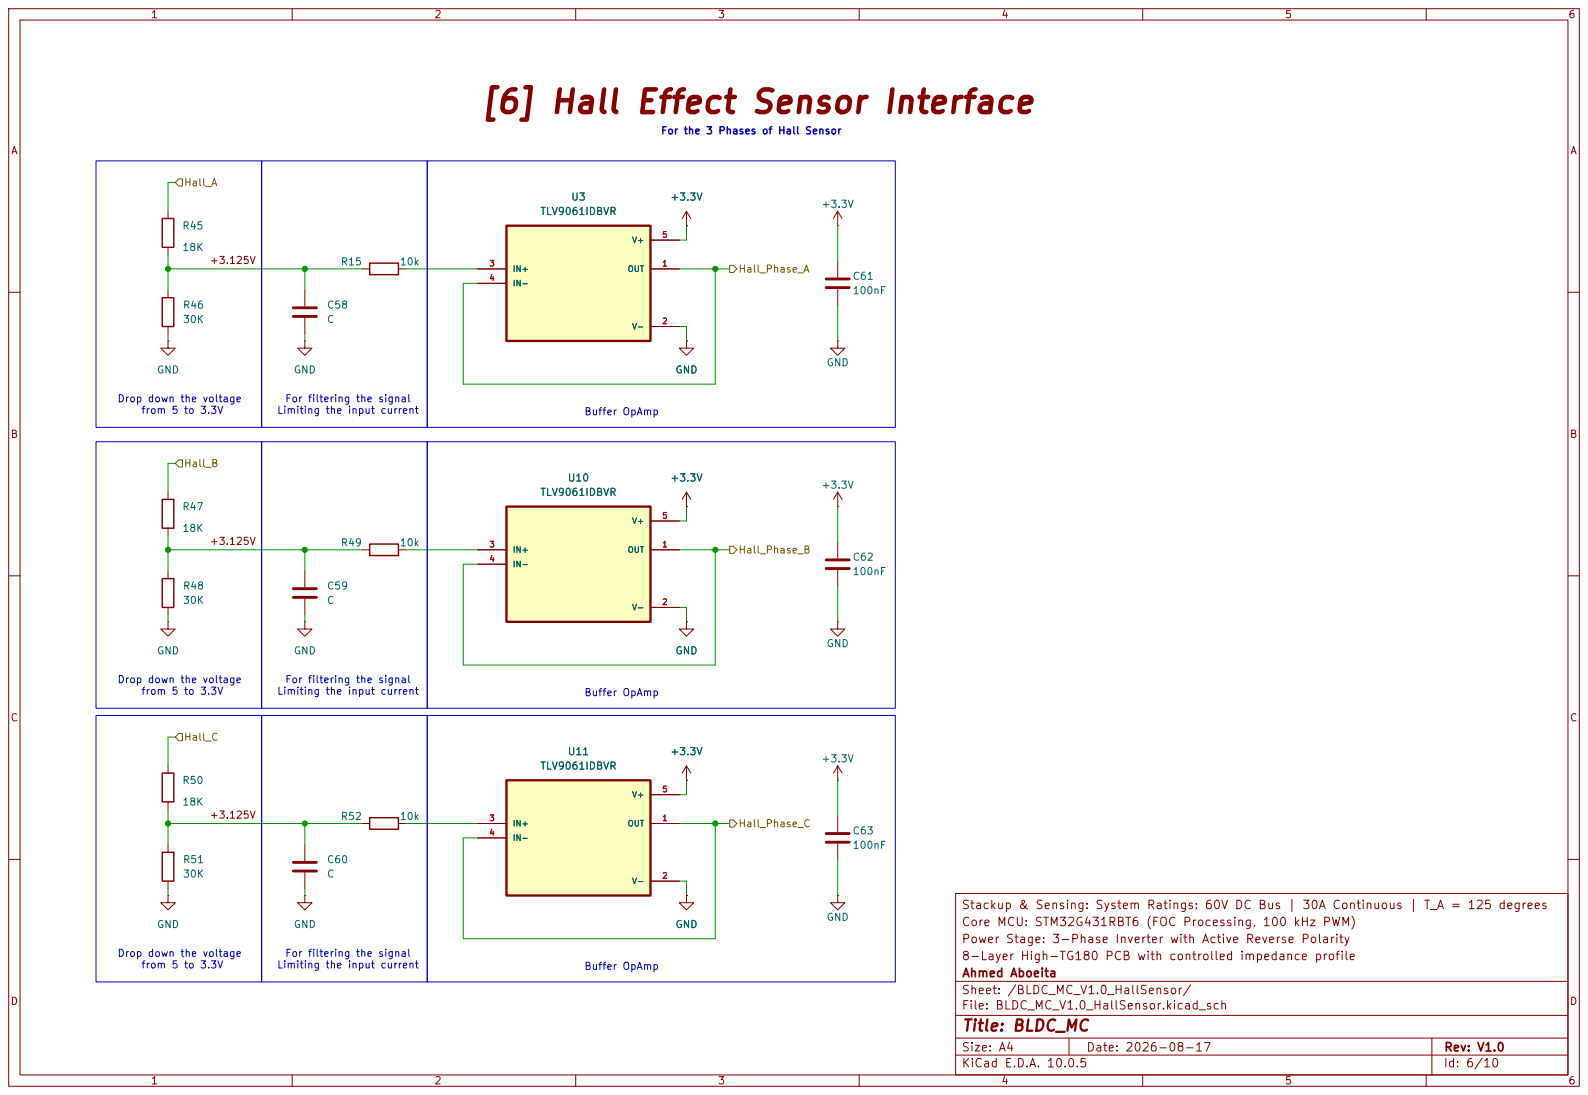
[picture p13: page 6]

For the 3 Phases of Hall Sensor [6] Hall Effect Sensor Interface
TLV9061IDBVR

Drop down the voltage
from 5 to 3.3V

For filtering the signal

Limiting the input current +3.125V Drop down the voltage

Stackup & Sensing: System Ratings: 60V DC Bus | 30A Continuous | T_A = 125 degrees
Core MCU: STM32G431RBT6 (FOC Processing, 100 kHz PWM)
Power Stage: 3-Phase Inverter with Active Reverse Polarity
8-Layer High-TG180 PCB with controlled impedance profile
Ahmed Aboeita
Sheet: /BLDC_MC_V1.0_HallSensor/
File: BLDC_MC_V1.0_HallSensor.kicad_sch
Title: BLDC_MC

Limiting the input current

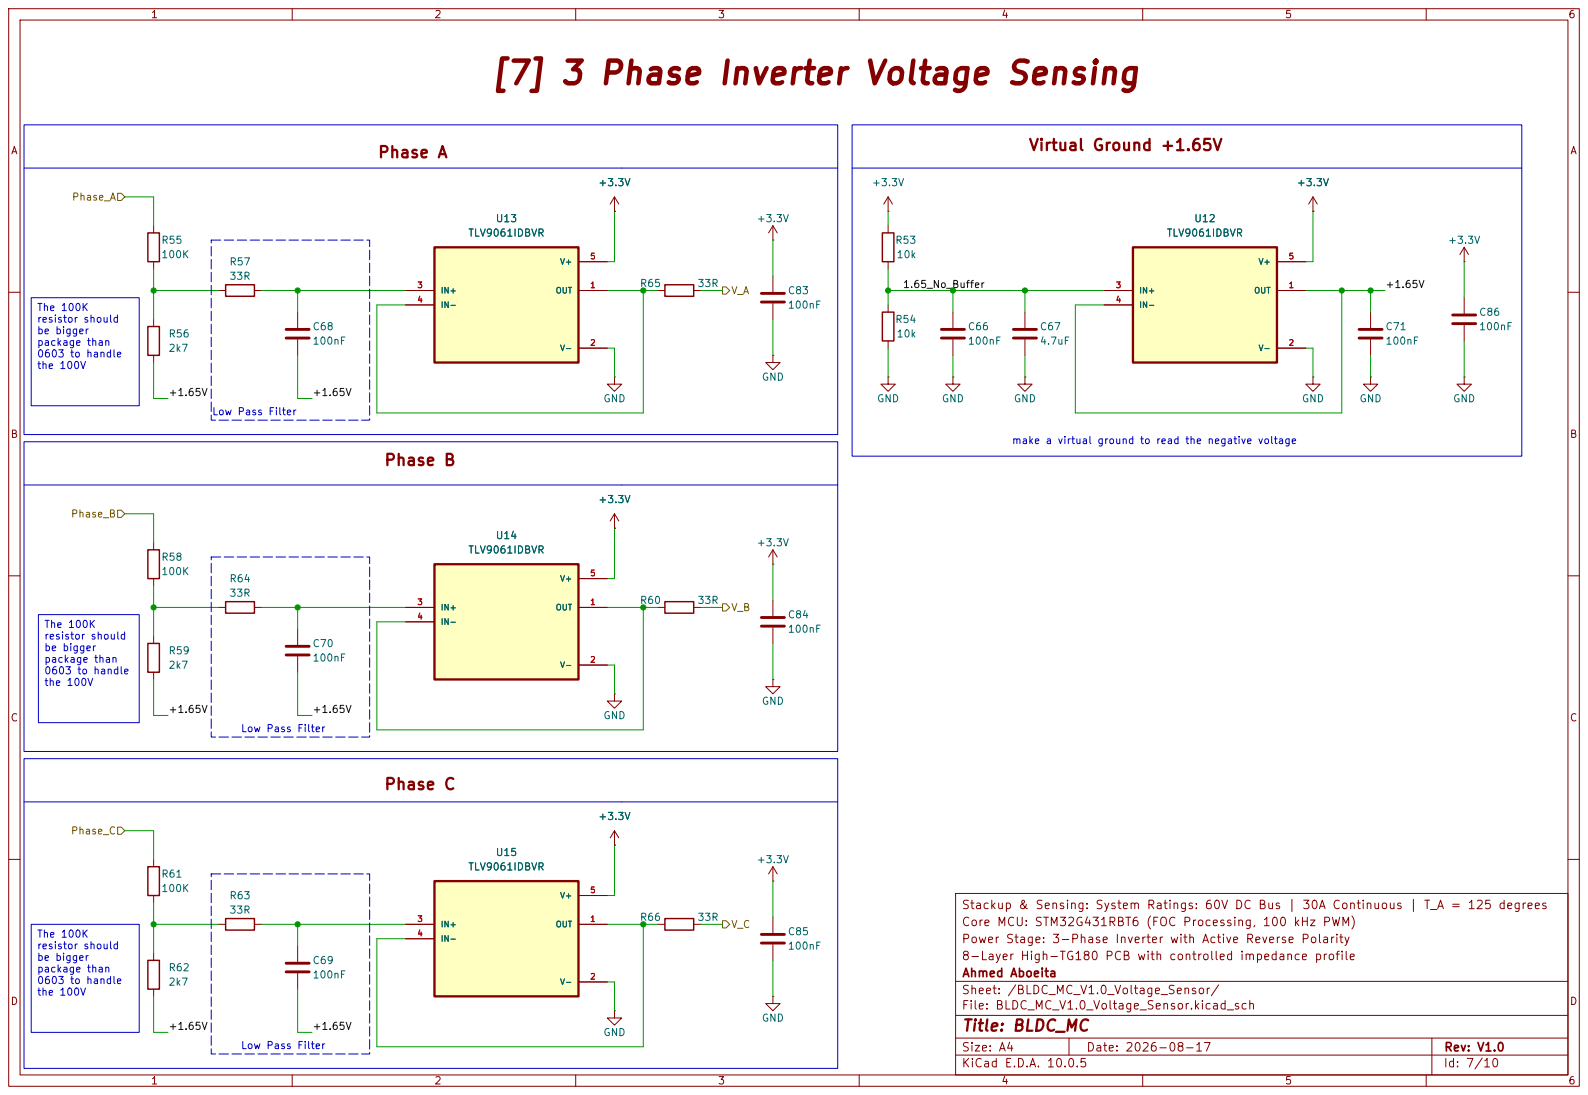
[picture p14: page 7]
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

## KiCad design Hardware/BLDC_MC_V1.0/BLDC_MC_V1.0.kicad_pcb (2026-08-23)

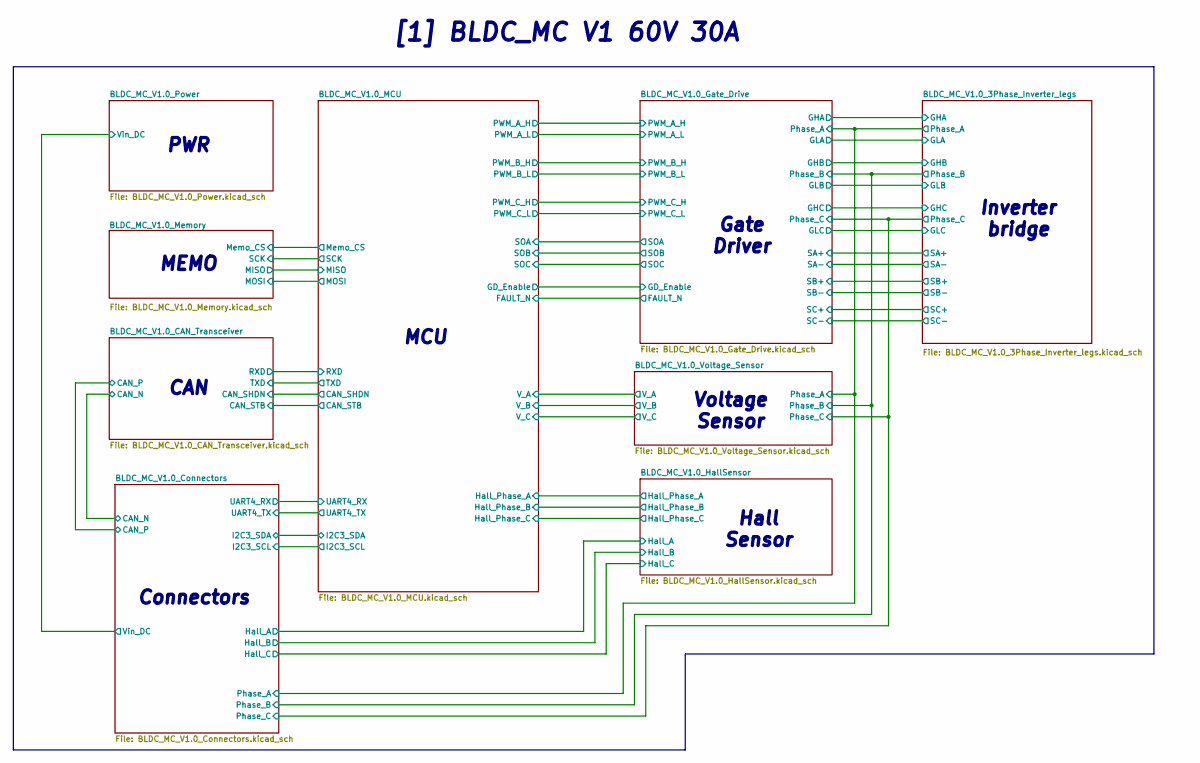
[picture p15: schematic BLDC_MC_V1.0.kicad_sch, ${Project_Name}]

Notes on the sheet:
Inverter bridge
MEMO
[1] BLDC_MC V1 60V 30A
Voltage Sensor
CAN
Gate Driver
Hall Sensor
Connectors
PWR
MCU

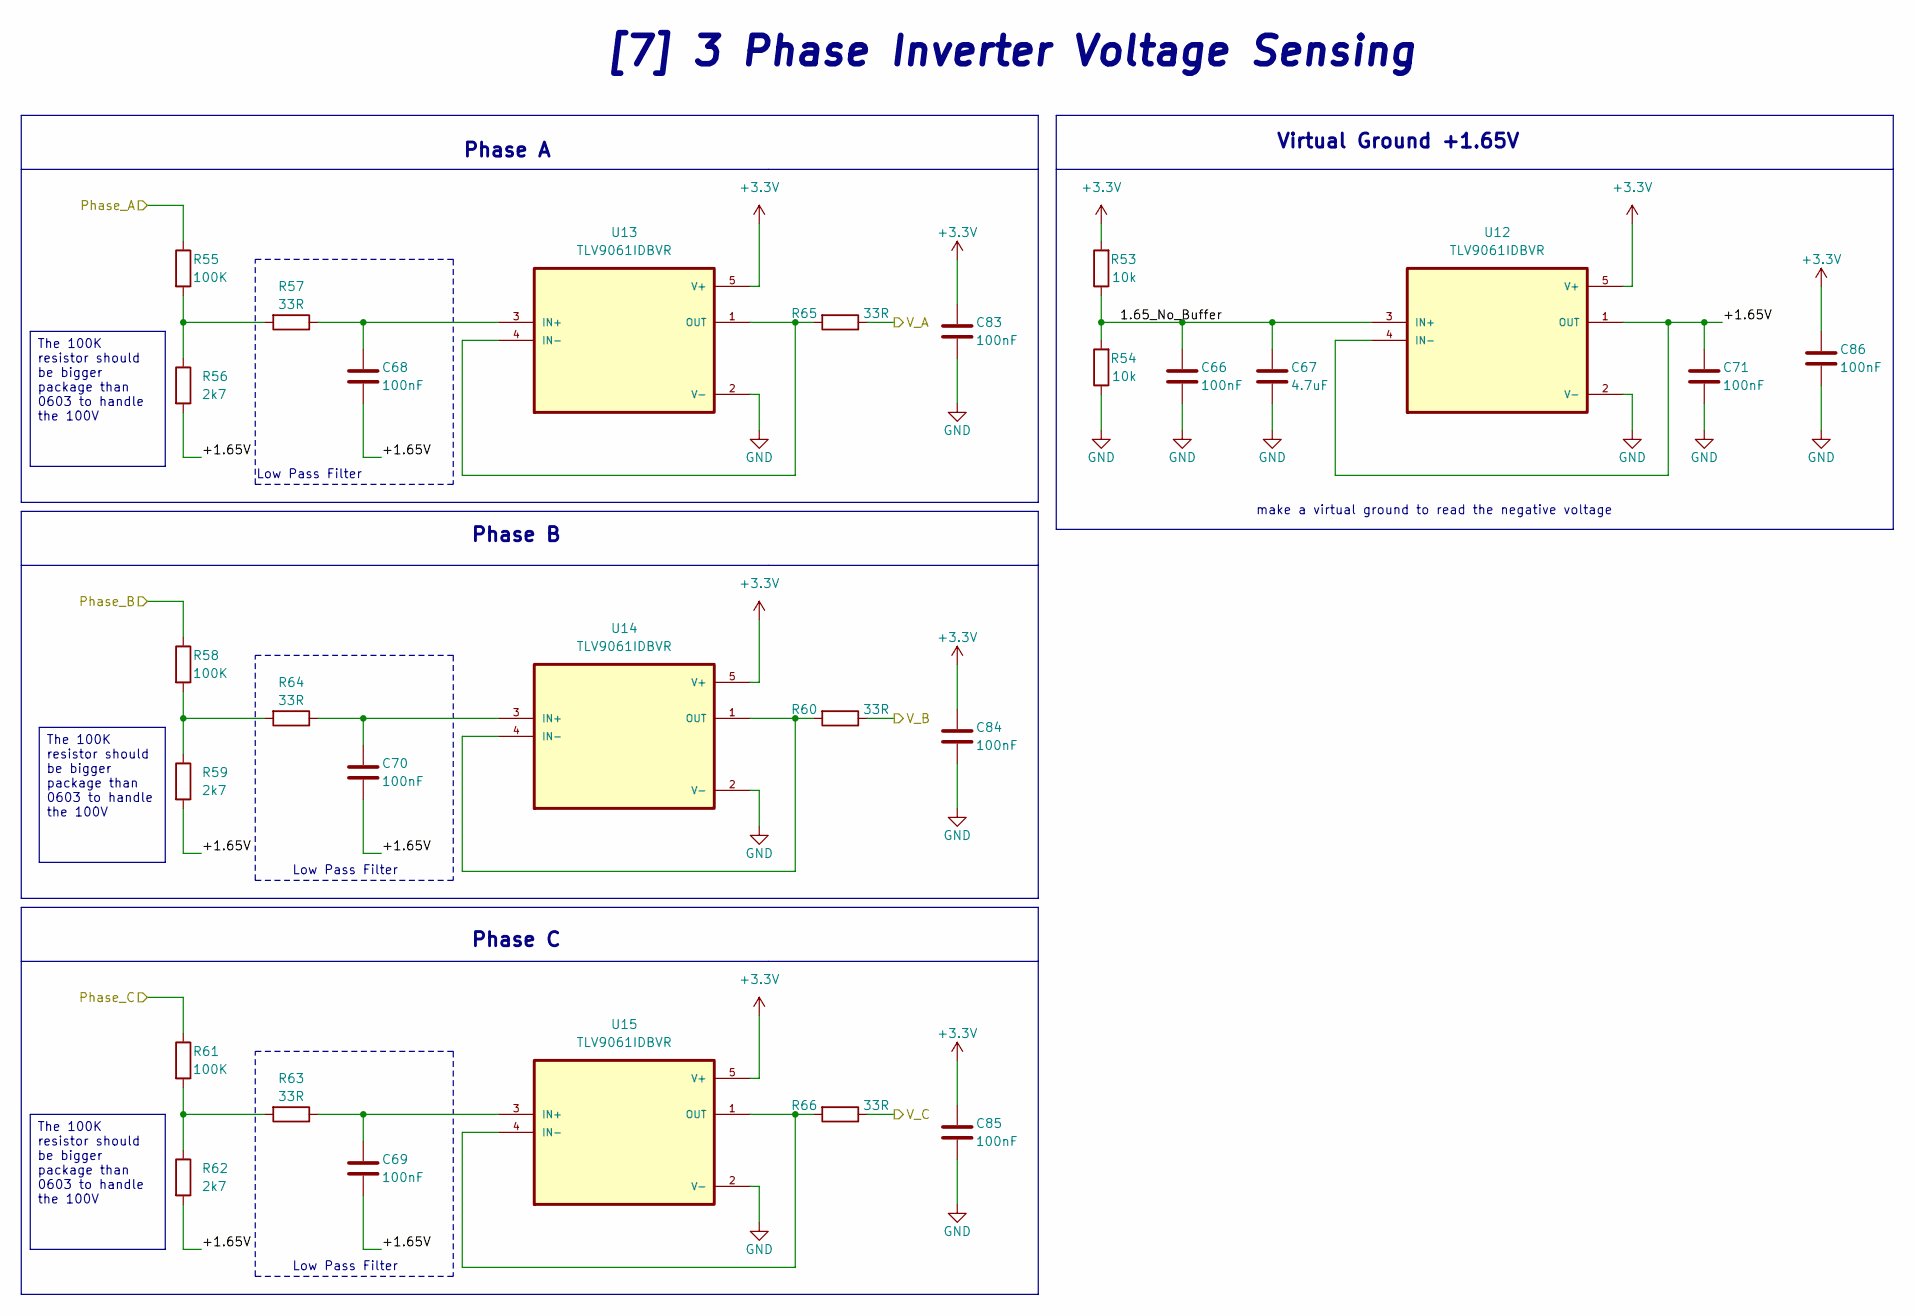
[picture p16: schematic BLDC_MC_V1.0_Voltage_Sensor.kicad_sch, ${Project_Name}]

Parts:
C66, C68, C69, C70, C71, C83, C84, C85, C86: 100nF; C_0805_2012Metric; LCSC_PN C28233
C67: 4.7uF; C_1206_3216Metric; LCSC_PN C51205
R53, R54: 10k; R_0603_1608Metric; LCSC_PN C95204
R55, R58, R61: 100K; R_1206_3216Metric; LCSC_PN C2907368
R56, R59, R62: 2k7; R_0603_1608Metric; LCSC_PN C705760
R57, R60, R63, R64, R65, R66: 33R; R_0603_1608Metric; LCSC_PN C108661
U12, U13, U14, U15: TLV9061IDBVR; SOT95P280X145-5N; LCSC_PN C398358

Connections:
+3.3V: C83.1, C84.1, C85.1, C86.1, R53.2, U12.5 (V+), U13.5 (V+), U14.5 (V+), U15.5 (V+); also elsewhere on the board
/BLDC_MC_V1.0_3Phase_Inverter_legs/Phase_A: R55.1; also elsewhere on the board
/BLDC_MC_V1.0_3Phase_Inverter_legs/Phase_B: R58.1; also elsewhere on the board
/BLDC_MC_V1.0_3Phase_Inverter_legs/Phase_C: R61.1; also elsewhere on the board
/BLDC_MC_V1.0_MCU/V_A: R65.1; also elsewhere on the board
/BLDC_MC_V1.0_MCU/V_B: R60.1; also elsewhere on the board
/BLDC_MC_V1.0_MCU/V_C: R66.1; also elsewhere on the board
/BLDC_MC_V1.0_Voltage_Sensor/1.65_No_Buffer: C66.1, C67.1, R53.1, R54.2, U12.3 (IN+)
/BLDC_MC_V1.0_Voltage_Sensor/+1.65V: C68.2, C69.2, C70.2, C71.1, R56.2, R59.2, R62.2, U12.1 (OUT), U12.4 (IN-)
GND: C66.2, C67.2, C71.2, C83.2, C84.2, C85.2, C86.2, R54.1, U12.2 (V-), U13.2 (V-), U14.2 (V-), U15.2 (V-); also elsewhere on the board
unnamed: R55.2, R56.1, R57.2
unnamed: R58.2, R59.1, R64.2
unnamed: R61.2, R62.1, R63.2
unnamed: C68.1, R57.1, U13.3 (IN+)
unnamed: R65.2, U13.1 (OUT), U13.4 (IN-)
unnamed: C70.1, R64.1, U14.3 (IN+)
unnamed: R60.2, U14.1 (OUT), U14.4 (IN-)
unnamed: C69.1, R63.1, U15.3 (IN+)
unnamed: R66.2, U15.1 (OUT), U15.4 (IN-)

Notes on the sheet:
Phase B
make a virtual ground to read the negative voltage
Virtual Ground +1.65V
Low Pass Filter
Phase C
Phase A
[7] 3 Phase Inverter Voltage Sensing
The 100K resistor should be bigger package than 0603 to handle the 100V

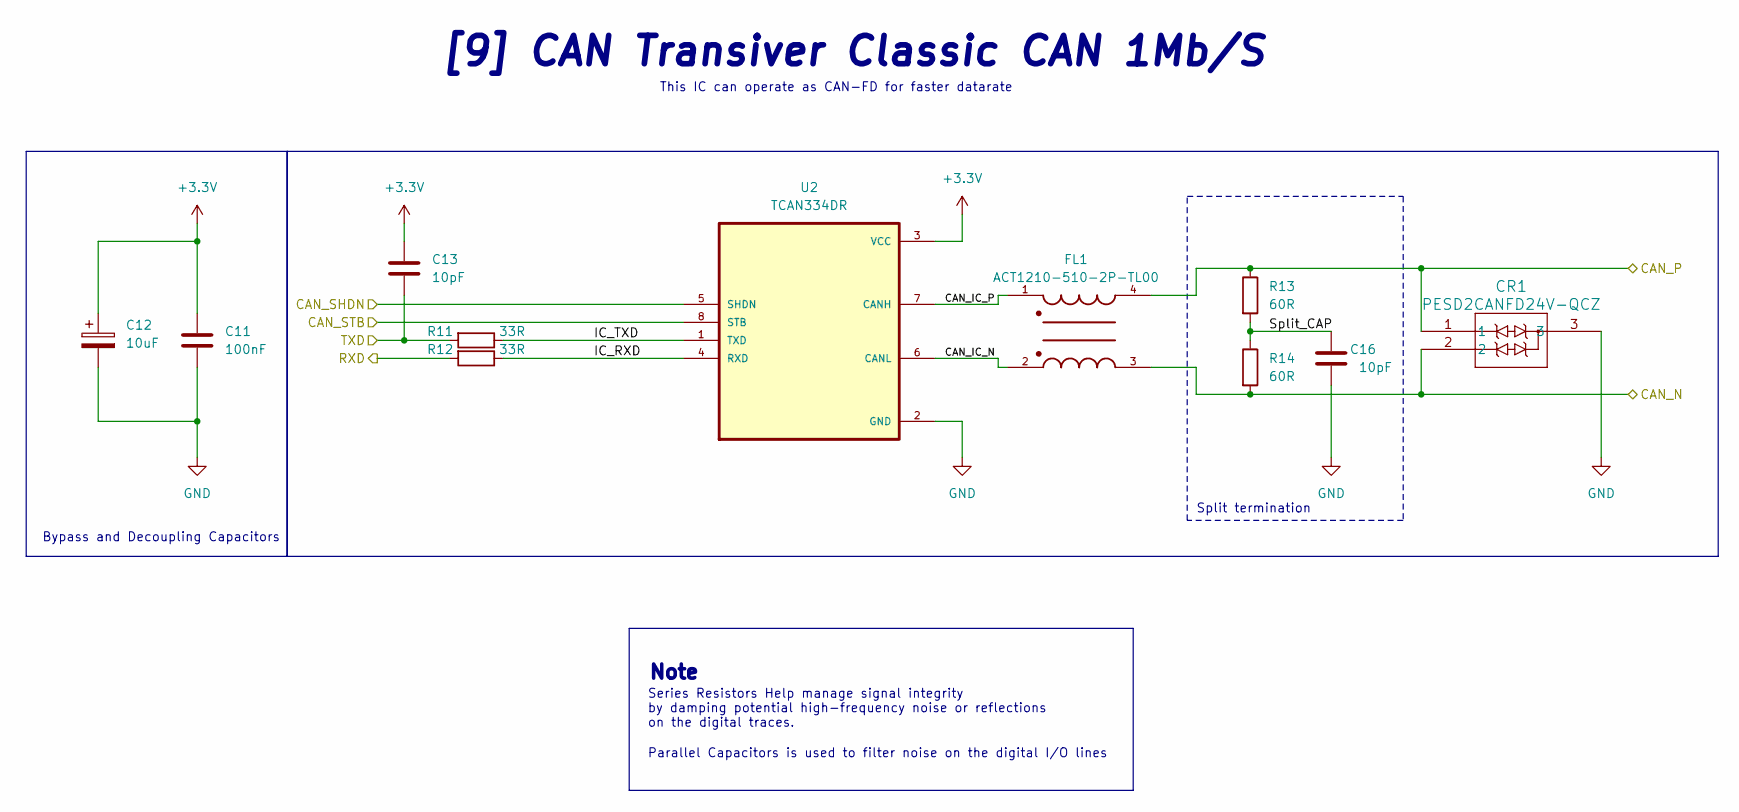
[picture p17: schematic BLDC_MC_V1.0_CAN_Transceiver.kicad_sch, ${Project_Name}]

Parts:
C11: 100nF; C_0805_2012Metric; LCSC_PN C28233
C12: 10uF; CP_EIA-3216-18_Kemet-A; LCSC_PN C7171
C13, C16: 10pF; C_0603_1608Metric; LCSC_PN C1634
CR1: PESD2CANFD24V-QCZ; DFN1412D-3_SOT8009_NEX; LCSC_PN C6251381
FL1: ACT1210-510-2P-TL00; FIL_ACT1210-510-2P-TL00; PARTREV 5/31/2021; LCSC_PN C95572
R11, R12: 33R; R_0603_1608Metric; LCSC_PN C108661
R13, R14: 60R; C_0603_1608Metric; LCSC_PN C166918
U2: TCAN334DR; SOIC127P599X175-8N

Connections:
+3.3V: C11.1, C12.1, C13.1, U2.3 (VCC); also elsewhere on the board
/BLDC_MC_V1.0_CAN_Transceiver/CAN_IC_N: FL1.2, U2.6 (CANL)
/BLDC_MC_V1.0_CAN_Transceiver/CAN_IC_P: FL1.1, U2.7 (CANH)
/BLDC_MC_V1.0_CAN_Transceiver/CAN_N: CR1.2, FL1.3, R14.2; also elsewhere on the board
/BLDC_MC_V1.0_CAN_Transceiver/CAN_P: CR1.1, FL1.4, R13.1; also elsewhere on the board
/BLDC_MC_V1.0_CAN_Transceiver/CAN_SHDN: U2.5 (SHDN); also elsewhere on the board
/BLDC_MC_V1.0_CAN_Transceiver/CAN_STB: U2.8 (STB); also elsewhere on the board
/BLDC_MC_V1.0_CAN_Transceiver/IC_RXD: R12.1, U2.4 (RXD)
/BLDC_MC_V1.0_CAN_Transceiver/IC_TXD: R11.1, U2.1 (TXD)
/BLDC_MC_V1.0_CAN_Transceiver/RXD: R12.2; also elsewhere on the board
/BLDC_MC_V1.0_CAN_Transceiver/Split_CAP: C16.1, R13.2, R14.1
/BLDC_MC_V1.0_CAN_Transceiver/TXD: C13.2, R11.2; also elsewhere on the board
GND: C11.2, C12.2, C16.2, CR1.3, U2.2 (GND); also elsewhere on the board

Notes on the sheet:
Series Resistors Help manage signal integrity by damping potential high-frequency noise or reflections on the digital traces.
Parallel Capacitors is used to filter noise on the digital I/O lines
Bypass and Decoupling Capacitors
[9] CAN Transiver Classic CAN 1Mb/S
Split termination
Note
This IC can operate as CAN-FD for faster datarate

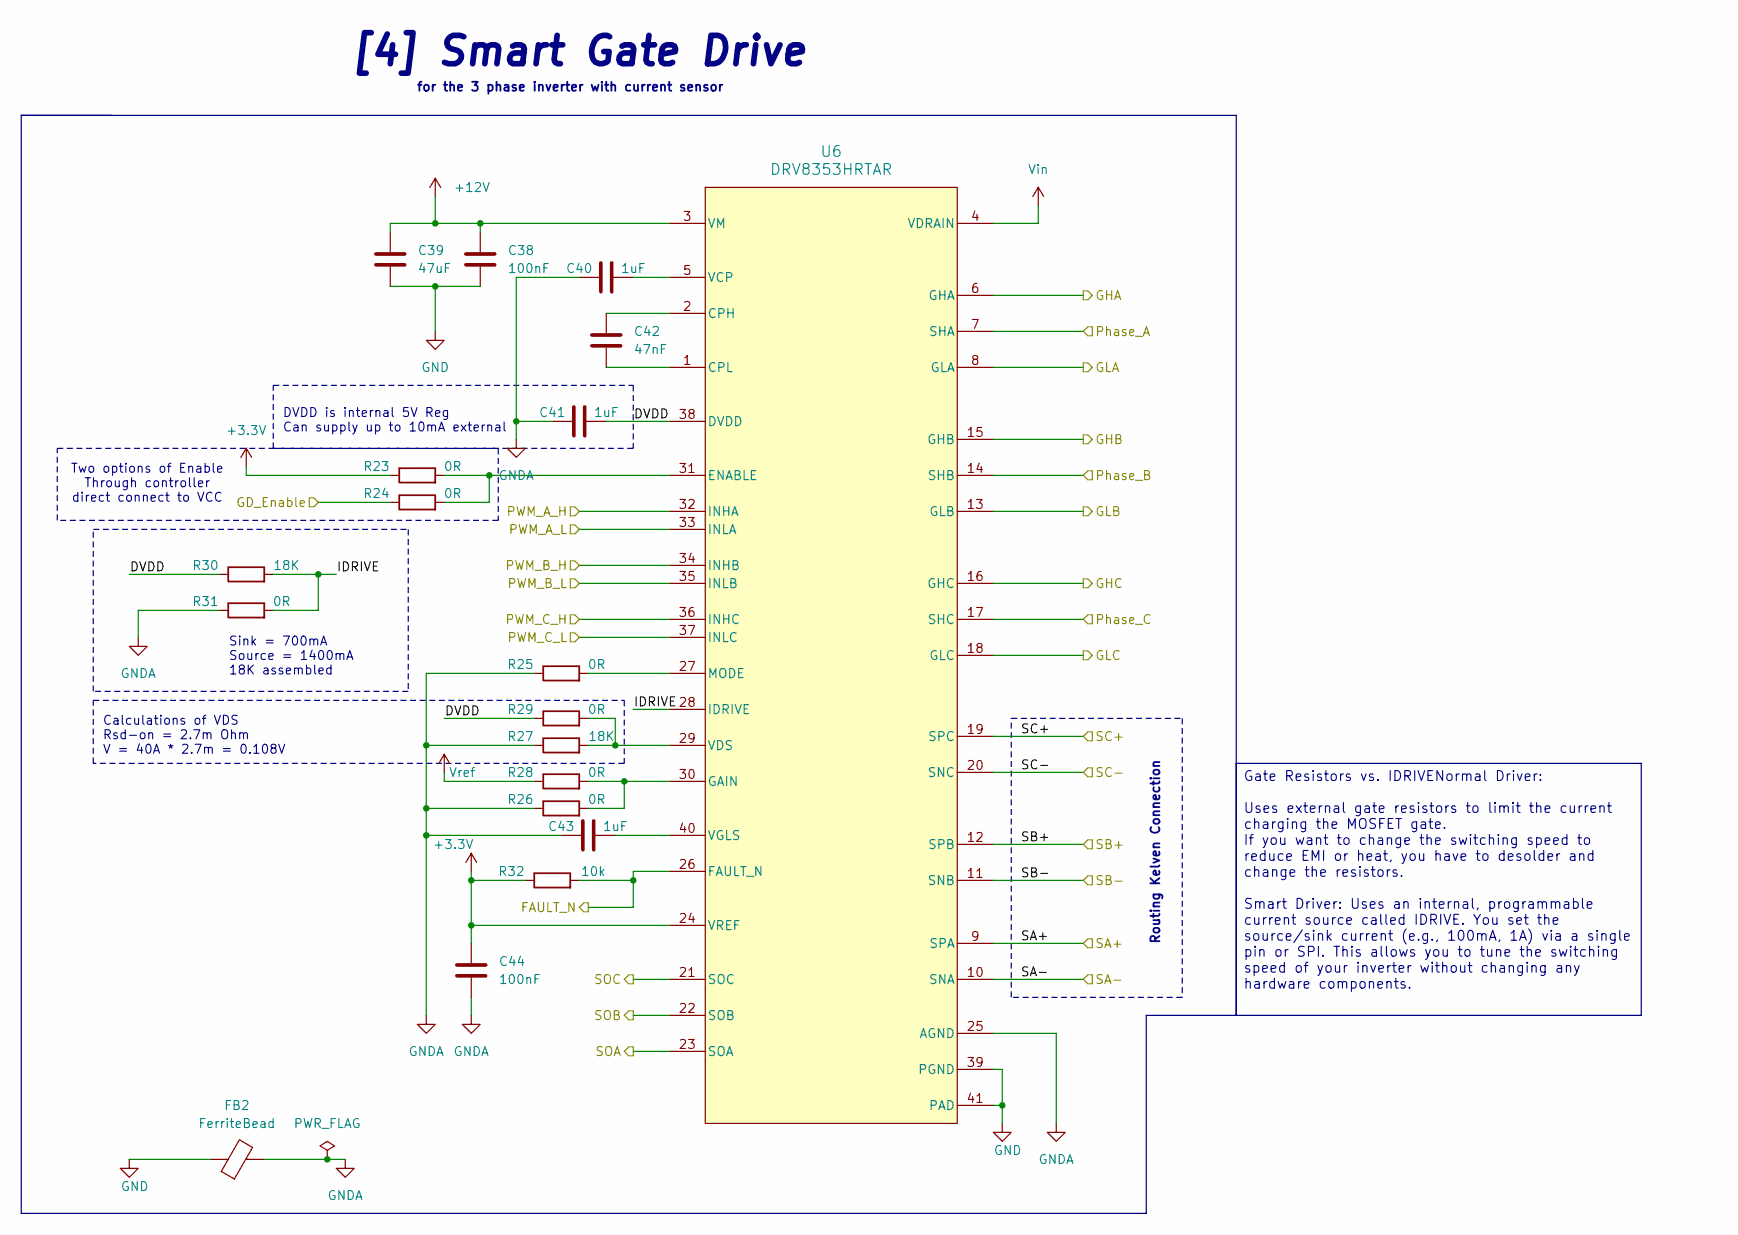
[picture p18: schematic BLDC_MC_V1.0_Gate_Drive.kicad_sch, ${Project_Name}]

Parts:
C38, C44: 100nF; C_0805_2012Metric; LCSC_PN C28233
C39: 47uF; C_1206_3216Metric; LCSC_PN C403725
C40, C41, C43: 1uF; C_0603_1608Metric; LCSC_PN C29936
C42: 47nF; C_0603_1608Metric; LCSC_PN C1622
FB2: FerriteBead; L_0603_1608Metric; LCSC_PN C19330
R23, R24, R25, R26, R28, R29, R31: 0R; R_0603_1608Metric; LCSC_PN C2906974
R27, R30: 18K; R_0603_1608Metric; LCSC_PN C309650
R32: 10k; R_0603_1608Metric; LCSC_PN C98220
U6: DRV8353HRTAR; RTA0040B; LCSC_PN C2150766

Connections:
+3.3V: C44.1, R23.1, R32.1, U6.24 (VREF); also elsewhere on the board
+12V: C38.1, C39.2, U6.3 (VM); also elsewhere on the board
/BLDC_MC_V1.0_3Phase_Inverter_legs/GHA: U6.6 (GHA); also elsewhere on the board
/BLDC_MC_V1.0_3Phase_Inverter_legs/GHB: U6.15 (GHB); also elsewhere on the board
/BLDC_MC_V1.0_3Phase_Inverter_legs/GHC: U6.16 (GHC); also elsewhere on the board
/BLDC_MC_V1.0_3Phase_Inverter_legs/GLA: U6.8 (GLA); also elsewhere on the board
/BLDC_MC_V1.0_3Phase_Inverter_legs/GLB: U6.13 (GLB); also elsewhere on the board
/BLDC_MC_V1.0_3Phase_Inverter_legs/GLC: U6.18 (GLC); also elsewhere on the board
/BLDC_MC_V1.0_3Phase_Inverter_legs/Phase_A: U6.7 (SHA); also elsewhere on the board
/BLDC_MC_V1.0_3Phase_Inverter_legs/Phase_B: U6.14 (SHB); also elsewhere on the board
/BLDC_MC_V1.0_3Phase_Inverter_legs/Phase_C: U6.17 (SHC); also elsewhere on the board
/BLDC_MC_V1.0_Gate_Drive/DVDD: C41.2, R29.1, R30.1, U6.38 (DVDD)
/BLDC_MC_V1.0_Gate_Drive/FAULT_N: R32.2, U6.26 (FAULT_N); also elsewhere on the board
/BLDC_MC_V1.0_Gate_Drive/GD_Enable: R24.1; also elsewhere on the board
/BLDC_MC_V1.0_Gate_Drive/IDRIVE: R30.2, R31.2, U6.28 (IDRIVE)
/BLDC_MC_V1.0_Gate_Drive/PWM_A_H: U6.32 (INHA); also elsewhere on the board
/BLDC_MC_V1.0_Gate_Drive/PWM_A_L: U6.33 (INLA); also elsewhere on the board
/BLDC_MC_V1.0_Gate_Drive/PWM_B_H: U6.34 (INHB); also elsewhere on the board
/BLDC_MC_V1.0_Gate_Drive/PWM_B_L: U6.35 (INLB); also elsewhere on the board
/BLDC_MC_V1.0_Gate_Drive/PWM_C_H: U6.36 (INHC); also elsewhere on the board
/BLDC_MC_V1.0_Gate_Drive/PWM_C_L: U6.37 (INLC); also elsewhere on the board
/BLDC_MC_V1.0_Gate_Drive/SA+: U6.9 (SPA); also elsewhere on the board
/BLDC_MC_V1.0_Gate_Drive/SA-: U6.10 (SNA); also elsewhere on the board
/BLDC_MC_V1.0_Gate_Drive/SB+: U6.12 (SPB); also elsewhere on the board
/BLDC_MC_V1.0_Gate_Drive/SB-: U6.11 (SNB); also elsewhere on the board
/BLDC_MC_V1.0_Gate_Drive/SC+: U6.19 (SPC); also elsewhere on the board
/BLDC_MC_V1.0_Gate_Drive/SC-: U6.20 (SNC); also elsewhere on the board
/BLDC_MC_V1.0_Gate_Drive/SOA: U6.23 (SOA); also elsewhere on the board
/BLDC_MC_V1.0_Gate_Drive/SOB: U6.22 (SOB); also elsewhere on the board
/BLDC_MC_V1.0_Gate_Drive/SOC: U6.21 (SOC); also elsewhere on the board
GND: C38.2, C39.1, FB2.1, U6.39 (PGND), U6.41 (PAD); also elsewhere on the board
GNDA: C40.1, C41.1, C43.1, C44.2, FB2.2, R25.1, R26.1, R27.1, R31.1, U6.25 (AGND)
unnamed: C42.1, U6.2 (CPH)
unnamed: C42.2, U6.1 (CPL)
unnamed: R23.2, R24.2, U6.31 (ENABLE)
unnamed: R26.2, R28.2, U6.30 (GAIN)
unnamed: R25.2, U6.27 (MODE)
unnamed: C40.2, U6.5 (VCP)
unnamed: R27.2, R29.2, U6.29 (VDS)
unnamed: C43.2, U6.40 (VGLS)
Vin: U6.4 (VDRAIN); also elsewhere on the board
Vref: R28.1; also elsewhere on the board

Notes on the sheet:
Calculations of VDS Rsd-on = 2.7m Ohm V = 40A * 2.7m = 0.108V
Two options of Enable Through controller direct connect to VCC
[4] Smart Gate Drive
Routing Kelven Connection
for the 3 phase inverter with current sensor
DVDD is internal 5V Reg Can supply up to 10mA external
Sink = 700mA Source = 1400mA 18K assembled
Gate Resistors vs. IDRIVENormal Driver: Uses external gate resistors to limit the current charging the MOSFET gate. If you want to change the switching speed to reduce EMI or heat, you have to desolder and change the resistors. Smart Driver: Uses an internal, programmable current source called IDRI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

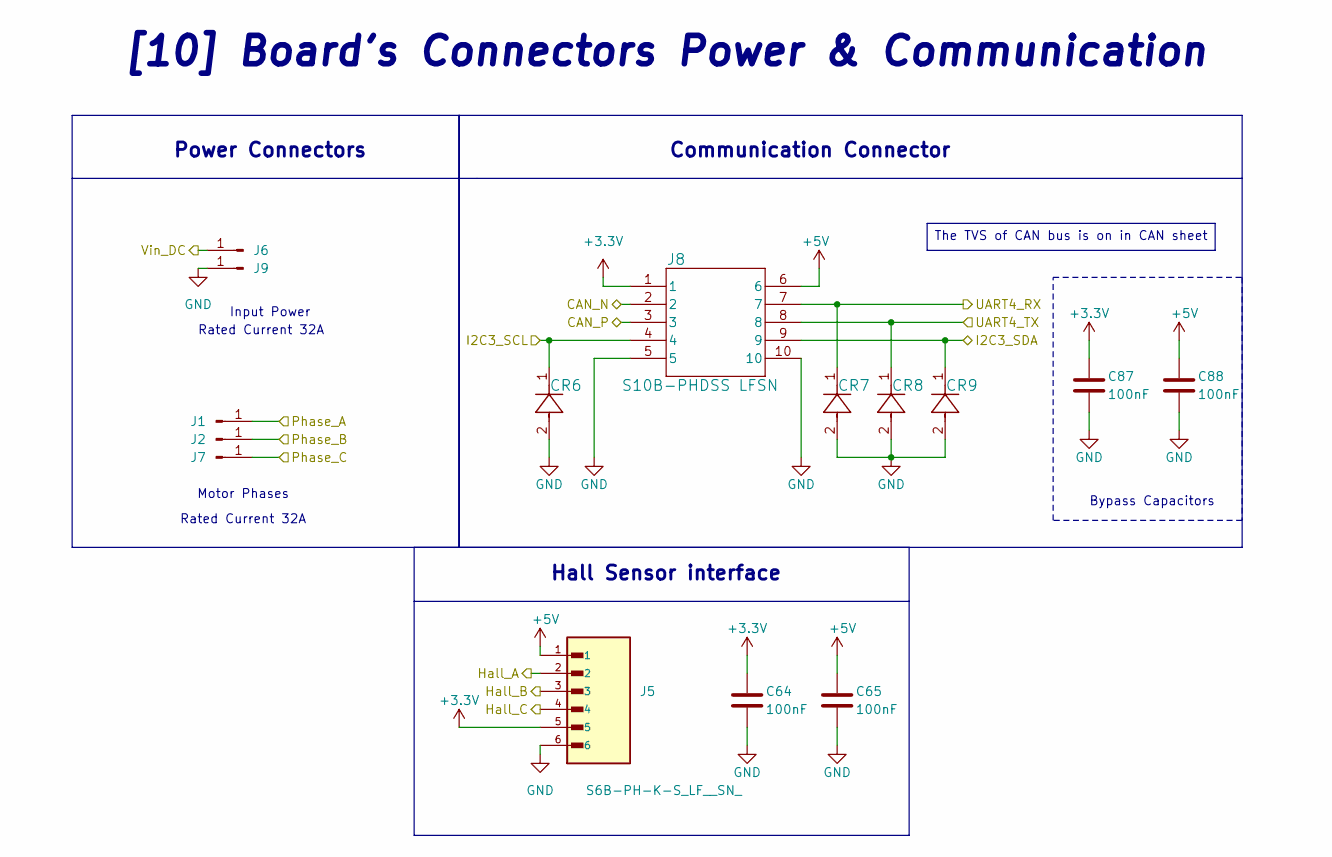
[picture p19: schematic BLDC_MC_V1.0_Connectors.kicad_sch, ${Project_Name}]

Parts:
C64, C65, C87, C88: 100nF; C_0805_2012Metric; LCSC_PN C28233
CR6, CR7, CR8, CR9: PESD3V3L1BA_115; DIODE_PESD3V3L1BA_115_NEX; LCSC_PN C552513
J1, J2, J6, J7, J9: Conn_01x01_Pin; PWR_CON_L
J5: S6B-PH-K-S_LF__SN_; JST_S6B-PH-K-S_LF__SN_; PARTREV R0; LCSC_PN C157920
J8: S10B-PHDSS LFSN; CONN_S10B-PHDSS_JST; LCSC_PN C161672

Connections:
+3.3V: C64.1, C87.1, J5.5, J8.1; also elsewhere on the board
+5V: C65.1, C88.1, J5.1, J8.6; also elsewhere on the board
/BLDC_MC_V1.0_3Phase_Inverter_legs/Phase_A: J1.1 (Pin_1_1); also elsewhere on the board
/BLDC_MC_V1.0_3Phase_Inverter_legs/Phase_B: J2.1 (Pin_1_1); also elsewhere on the board
/BLDC_MC_V1.0_3Phase_Inverter_legs/Phase_C: J7.1 (Pin_1_1); also elsewhere on the board
/BLDC_MC_V1.0_CAN_Transceiver/CAN_N: J8.2; also elsewhere on the board
/BLDC_MC_V1.0_CAN_Transceiver/CAN_P: J8.3; also elsewhere on the board
/BLDC_MC_V1.0_Connectors/Hall_A: J5.2; also elsewhere on the board
/BLDC_MC_V1.0_Connectors/Hall_B: J5.3; also elsewhere on the board
/BLDC_MC_V1.0_Connectors/Hall_C: J5.4; also elsewhere on the board
/BLDC_MC_V1.0_Connectors/I2C3_SCL: CR6.1, J8.4; also elsewhere on the board
/BLDC_MC_V1.0_Connectors/I2C3_SDA: CR9.1, J8.9; also elsewhere on the board
/BLDC_MC_V1.0_Connectors/UART4_RX: CR7.1, J8.7; also elsewhere on the board
/BLDC_MC_V1.0_Connectors/UART4_TX: CR8.1, J8.8; also elsewhere on the board
/BLDC_MC_V1.0_Connectors/Vin_DC: J6.1 (Pin_1_1); also elsewhere on the board
GND: C64.2, C65.2, C87.2, C88.2, CR6.2, CR7.2, CR8.2, CR9.2, J5.6, J8.5, J8.10, J9.1 (Pin_1_1); also elsewhere on the board

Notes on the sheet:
Rated Current 32A
Motor Phases
[10] Board's Connectors Power & Communication
Communication Connector
Bypass Capacitors
Hall Sensor interface
Input Power
Power Connectors
The TVS of CAN bus is on in CAN sheet

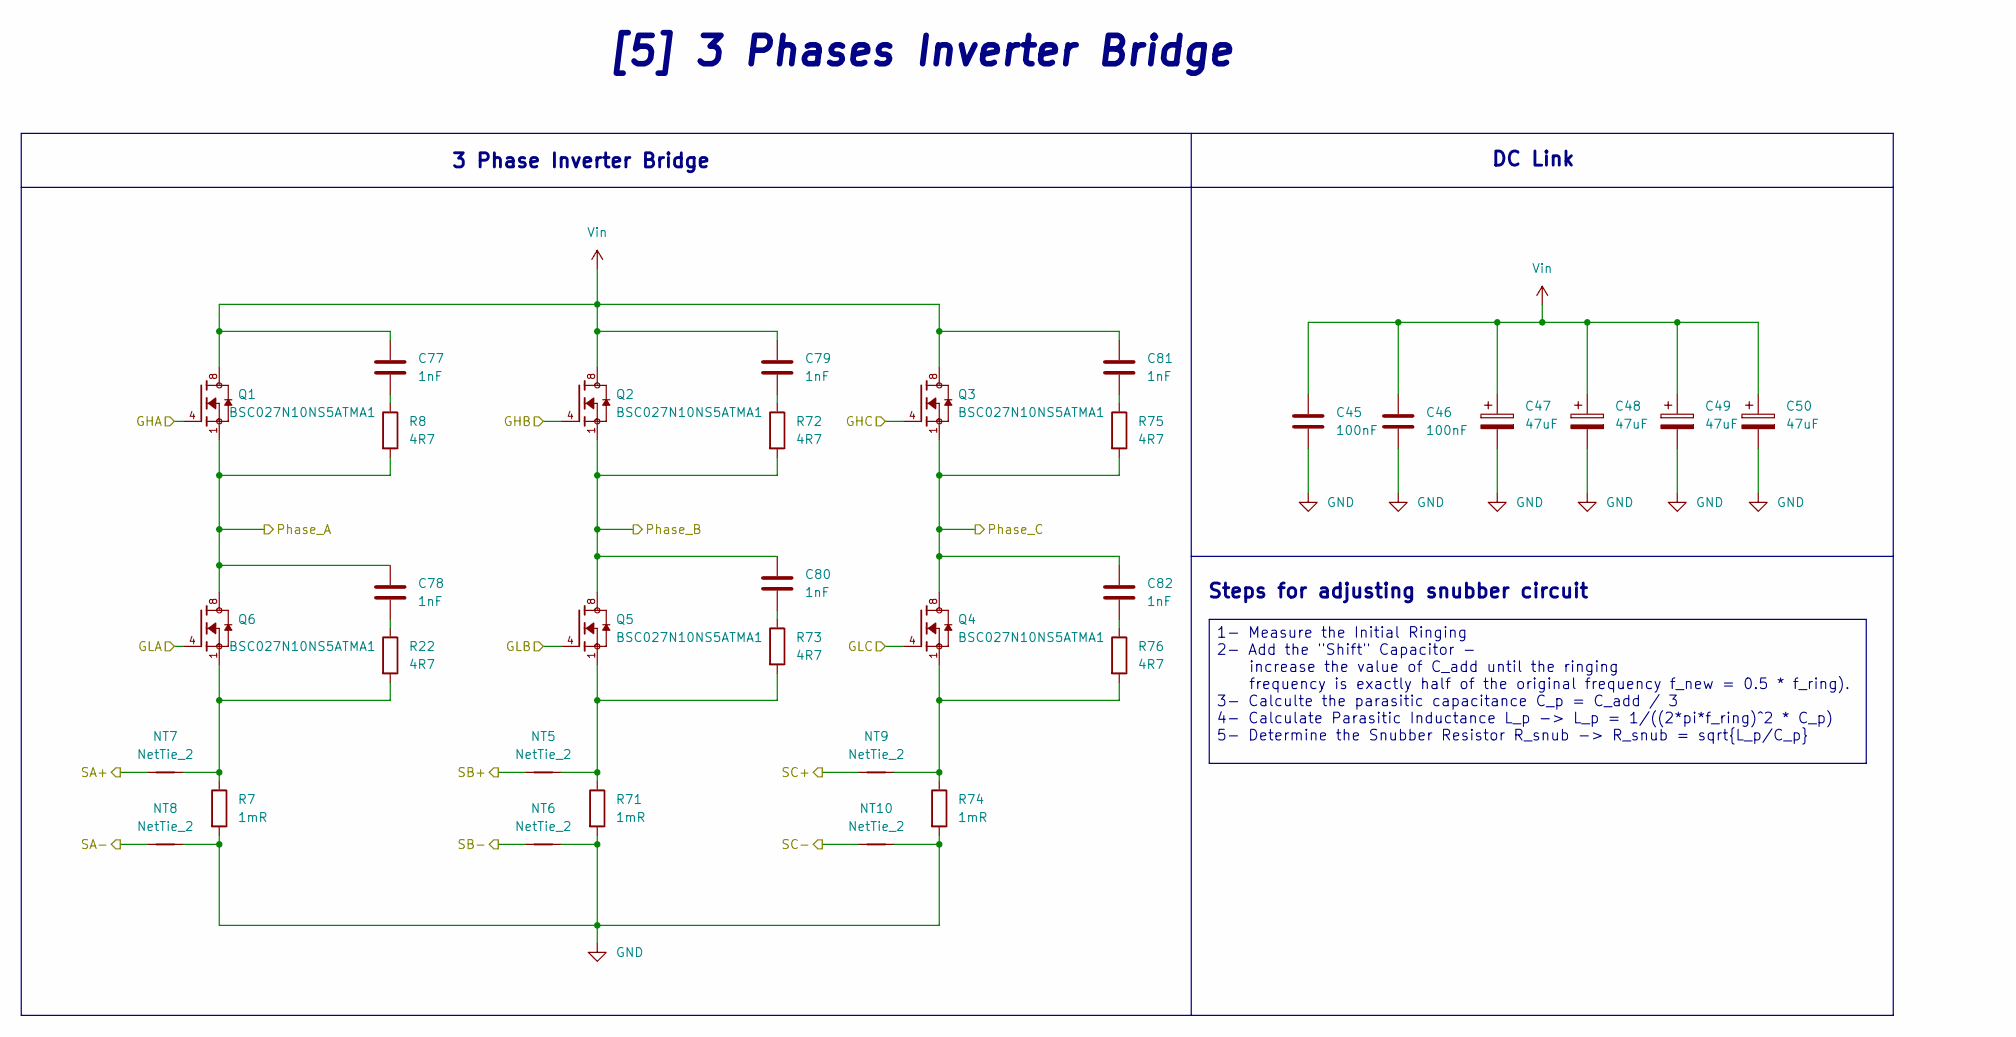
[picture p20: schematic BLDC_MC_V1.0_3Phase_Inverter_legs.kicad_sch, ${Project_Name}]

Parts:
C45, C46: 100nF; C_0805_2012Metric; LCSC_PN C28233
C47, C48, C49, C50: 47uF; CP_Elec_10x10.5; LCSC_PN C46528101
C77, C78, C79, C80, C81, C82: 1nF; C_1206_3216Metric; LCSC_PN C23631
NT5, NT6, NT7, NT8, NT9, NT10: NetTie_2; NetTie-2_SMD_Pad0.5mm
Q1, Q2, Q3, Q4, Q5, Q6: BSC027N10NS5ATMA1; PG-TSON-8-3_INF; PARTREV 2.1; LCSC_PN C534315
R7, R71, R74: 1mR; R_2512_6332Metric; LCSC_PN C7419999
R8, R22, R72, R73, R75, R76: 4R7; R_2512_6332Metric_Pad1.40x3.35mm_HandSolder; LCSC_PN C25489

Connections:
/BLDC_MC_V1.0_3Phase_Inverter_legs/GHA: Q1.4; also elsewhere on the board
/BLDC_MC_V1.0_3Phase_Inverter_legs/GHB: Q2.4; also elsewhere on the board
/BLDC_MC_V1.0_3Phase_Inverter_legs/GHC: Q3.4; also elsewhere on the board
/BLDC_MC_V1.0_3Phase_Inverter_legs/GLA: Q6.4; also elsewhere on the board
/BLDC_MC_V1.0_3Phase_Inverter_legs/GLB: Q5.4; also elsewhere on the board
/BLDC_MC_V1.0_3Phase_Inverter_legs/GLC: Q4.4; also elsewhere on the board
/BLDC_MC_V1.0_3Phase_Inverter_legs/Phase_A: C78.1, Q1.1, Q1.2, Q1.3, Q6.5, Q6.6, Q6.7, Q6.8, R8.2; also elsewhere on the board
/BLDC_MC_V1.0_3Phase_Inverter_legs/Phase_B: C80.1, Q2.1, Q2.2, Q2.3, Q5.5, Q5.6, Q5.7, Q5.8, R72.2; also elsewhere on the board
/BLDC_MC_V1.0_3Phase_Inverter_legs/Phase_C: C82.1, Q3.1, Q3.2, Q3.3, Q4.5, Q4.6, Q4.7, Q4.8, R75.2; also elsewhere on the board
/BLDC_MC_V1.0_Gate_Drive/SA+: NT7.1; also elsewhere on the board
/BLDC_MC_V1.0_Gate_Drive/SA-: NT8.1; also elsewhere on the board
/BLDC_MC_V1.0_Gate_Drive/SB+: NT5.1; also elsewhere on the board
/BLDC_MC_V1.0_Gate_Drive/SB-: NT6.1; also elsewhere on the board
/BLDC_MC_V1.0_Gate_Drive/SC+: NT9.1; also elsewhere on the board
/BLDC_MC_V1.0_Gate_Drive/SC-: NT10.1; also elsewhere on the board
GND: C45.2, C46.2, C47.2, C48.2, C49.2, C50.2, NT6.2, NT8.2, NT10.2, R7.2, R71.2, R74.2; also elsewhere on the board
unnamed: C77.2, R8.1
unnamed: C78.2, R22.1
unnamed: C79.2, R72.1
unnamed: C80.2, R73.1
unnamed: C81.2, R75.1
unnamed: C82.2, R76.1
unnamed: NT5.2, Q5.1, Q5.2, Q5.3, R71.1, R73.2
unnamed: NT7.2, Q6.1, Q6.2, Q6.3, R7.1, R22.2
unnamed: NT9.2, Q4.1, Q4.2, Q4.3, R74.1, R76.2
Vin: C45.1, C46.1, C47.1, C48.1, C49.1, C50.1, C77.1, C79.1, C81.1, Q1.5, Q1.6, Q1.7, Q1.8, Q2.5, Q2.6, Q2.7, Q2.8, Q3.5, Q3.6, Q3.7, Q3.8; also elsewhere on the board

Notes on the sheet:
[5] 3 Phases Inverter Bridge
3 Phase Inverter Bridge
Steps for adjusting snubber circuit
DC Link
1- Measure the Initial Ringing 2- Add the "Shift" Capacitor - increase the value of C_add until the ringing frequency is exactly half of the original frequency f_new = 0.5 * f_ring). 3- Calculte the parasitic capacitance C_p = C_add / 3 4- Calculate Parasitic Inductance L_p -> L_p = 1/((2*pi*f_ring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

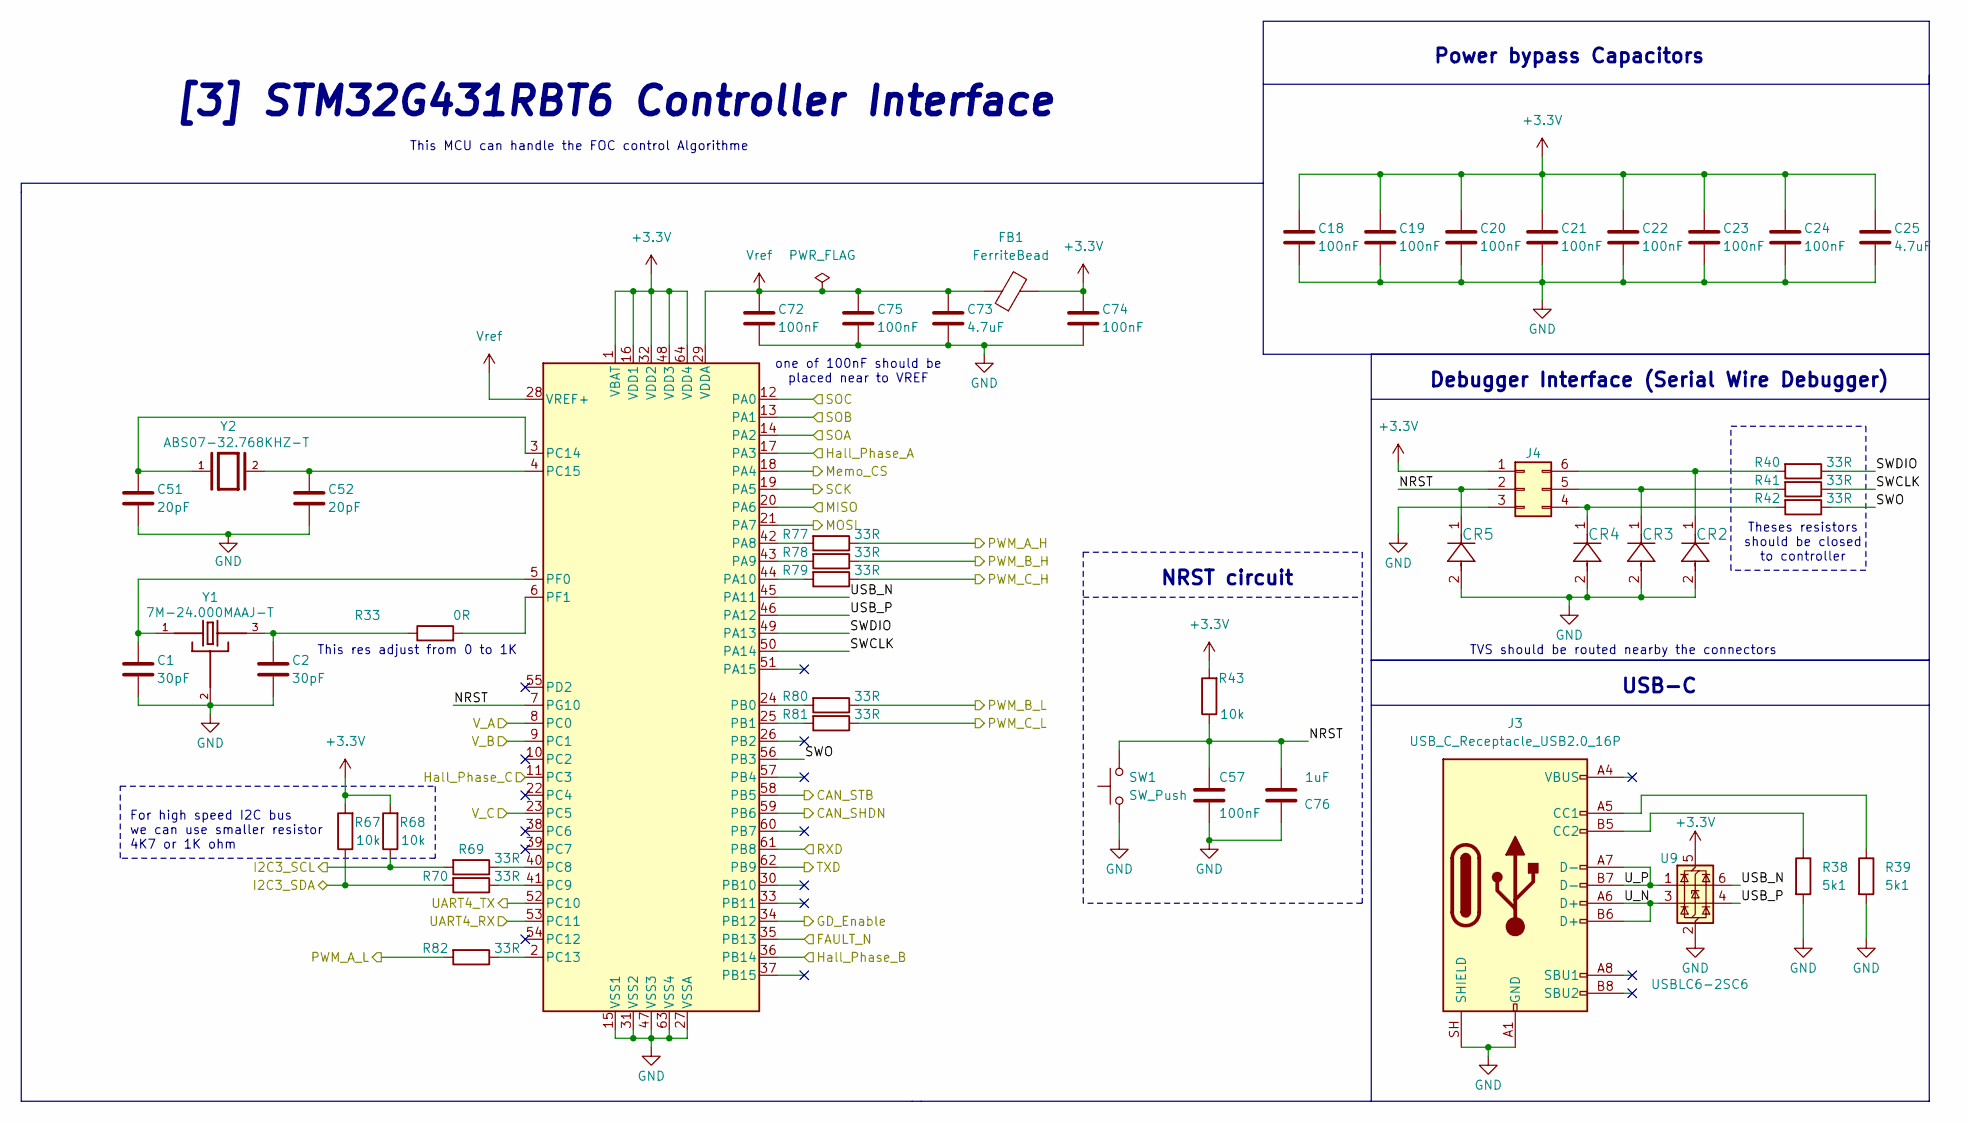
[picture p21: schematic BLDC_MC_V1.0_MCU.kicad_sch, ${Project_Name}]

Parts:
C1, C2: 30pF; C_0603_1608Metric; LCSC_PN C113797
C18, C19, C20, C21, C22, C23, C24, C57, C72, C74, C75: 100nF; C_0805_2012Metric; LCSC_PN C28233
C25, C73: 4.7uF; C_1206_3216Metric; LCSC_PN C51205
C51, C52: 20pF; C_0603_1608Metric; LCSC_PN C1648
C76: 1uF; C_0603_1608Metric; LCSC_PN C29936
CR2, CR3, CR4, CR5: PESD3V3L1BA_115; DIODE_PESD3V3L1BA_115_NEX; LCSC_PN C552513
FB1: FerriteBead; L_0603_1608Metric; LCSC_PN C19330
J3: USB_C_Receptacle_USB2.0_16P; USB_C_Receptacle_GCT_USB4105-xx-A_16P_TopMnt_Horizontal
J4: Conn_02x03_Counter_Clockwise; PinHeader_2x03_P2.54mm_Vertical
R33: 0R; R_0603_1608Metric; LCSC_PN C2906974
R38, R39: 5k1; R_0603_1608Metric; LCSC_PN C23186
R40, R41, R42, R69, R70, R77, R78, R79, R80, R81, R82: 33R; R_0603_1608Metric; LCSC_PN C108661
R43: 10k; R_0603_1608Metric; LCSC_PN C98220
R67, R68: 10k; R_0603_1608Metric; LCSC_PN C95204
SW1: SW_Push; SW_Push_1P1T_NO_E-Switch_TL3301NxxxxxG
U4: STM32G431RBT6; LQFP64-10x10mm; LCSC_PN C431633
U9: USBLC6-2SC6; SOT-23-6
Y1: 7M-24.000MAAJ-T; XTAL_7M-24.000MAAJ-T; LCSC_PN C2450233
Y2: ABS07-32.768KHZ-T; XTAL_ABS07-32.768KHZ-T; PARTREV 08.19.15; LCSC_PN C130253

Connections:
+3.3V: C18.1, C19.1, C20.1, C21.1, C22.1, C23.1, C24.1, C25.1, C74.1, FB1.2, J4.1, R43.2, R67.2, R68.2, U4.1 (VBAT), U4.16 (VDD1), U4.32 (VDD2), U4.48 (VDD3), U4.64 (VDD4), U9.5 (VBUS); also elsewhere on the board
/BLDC_MC_V1.0_CAN_Transceiver/CAN_SHDN: U4.59 (PB6); also elsewhere on the board
/BLDC_MC_V1.0_CAN_Transceiver/CAN_STB: U4.58 (PB5); also elsewhere on the board
/BLDC_MC_V1.0_CAN_Transceiver/RXD: U4.61 (PB8); also elsewhere on the board
/BLDC_MC_V1.0_CAN_Transceiver/TXD: U4.62 (PB9); also elsewhere on the board
/BLDC_MC_V1.0_Connectors/I2C3_SCL: R68.1, R69.2; also elsewhere on the board
/BLDC_MC_V1.0_Connectors/I2C3_SDA: R67.1, R70.2; also elsewhere on the board
/BLDC_MC_V1.0_Connectors/UART4_RX: U4.53 (PC11); also elsewhere on the board
/BLDC_MC_V1.0_Connectors/UART4_TX: U4.52 (PC10); also elsewhere on the board
/BLDC_MC_V1.0_Gate_Drive/FAULT_N: U4.35 (PB13); also elsewhere on the board
/BLDC_MC_V1.0_Gate_Drive/GD_Enable: U4.34 (PB12); also elsewhere on the board
/BLDC_MC_V1.0_Gate_Drive/PWM_A_H: R77.1; also elsewhere on the board
/BLDC_MC_V1.0_Gate_Drive/PWM_A_L: R82.2; also elsewhere on the board
/BLDC_MC_V1.0_Gate_Drive/PWM_B_H: R78.1; also elsewhere on the board
/BLDC_MC_V1.0_Gate_Drive/PWM_B_L: R80.1; also elsewhere on the board
/BLDC_MC_V1.0_Gate_Drive/PWM_C_H: R79.1; also elsewhere on the board
/BLDC_MC_V1.0_Gate_Drive/PWM_C_L: R81.1; also elsewhere on the board
/BLDC_MC_V1.0_Gate_Drive/SOA: U4.14 (PA2); also elsewhere on the board
/BLDC_MC_V1.0_Gate_Drive/SOB: U4.13 (PA1); also elsewhere on the board
/BLDC_MC_V1.0_Gate_Drive/SOC: U4.12 (PA0); also elsewhere on the board
/BLDC_MC_V1.0_HallSensor/Hall_Phase_A: U4.17 (PA3); also elsewhere on the board
/BLDC_MC_V1.0_HallSensor/Hall_Phase_B: U4.36 (PB14); also elsewhere on the board
/BLDC_MC_V1.0_HallSensor/Hall_Phase_C: U4.11 (PC3); also elsewhere on the board
/BLDC_MC_V1.0_MCU/MISO: U4.20 (PA6); also elsewhere on the board
/BLDC_MC_V1.0_MCU/MOSI: U4.21 (PA7); also elsewhere on the board
/BLDC_MC_V1.0_MCU/Memo_CS: U4.18 (PA4); also elsewhere on the board
/BLDC_MC_V1.0_MCU/NRST: C57.1, C76.2, CR5.1, J4.2, R43.1, SW1.2, U4.7 (PG10)
/BLDC_MC_V1.0_MCU/SCK: U4.19 (PA5); also elsewhere on the board
/BLDC_MC_V1.0_MCU/SWCLK: R41.1, U4.50 (PA14)
/BLDC_MC_V1.0_MCU/SWDIO: R40.1, U4.49 (PA13)
/BLDC_MC_V1.0_MCU/SWO: R42.1, U4.56 (PB3)
/BLDC_MC_V1.0_MCU/USB_N: U4.45 (PA11), U9.6 (I/O1)
/BLDC_MC_V1.0_MCU/USB_P: U4.46 (PA12), U9.4 (I/O2)
/BLDC_MC_V1.0_MCU/U_N: J3.A6 (D+), J3.B6 (D+), U9.3 (I/O2)
/BLDC_MC_V1.0_MCU/U_P: J3.A7 (D-), J3.B7 (D-), U9.1 (I/O1)
/BLDC_MC_V1.0_MCU/V_A: U4.8 (PC0); also elsewhere on the board
/BLDC_MC_V1.0_MCU/V_B: U4.9 (PC1); also elsewhere on the board
/BLDC_MC_V1.0_MCU/V_C: U4.23 (PC5); also elsewhere on the board
GND: C1.2, C2.2, C18.2, C19.2, C20.2, C21.2, C22.2, C23.2, C24.2, C25.2, C51.2, C52.2, C57.2, C72.2, C73.2, C74.2, C75.2, C76.1, CR2.2, CR3.2, CR4.2, CR5.2, J3.A1 (GND), J3.A12 (GND), J3.SH (SHIELD), J4.3, R38.2, R39.2, SW1.1, U4.15 (VSS1), U4.27 (VSSA), U4.31 (VSS2), U4.47 (VSS3), U4.63 (VSS4), U9.2 (GND), Y1.2, Y1.4; also elsewhere on the board
unnamed: C2.1, R33.1, Y1.3
unnamed: J3.A5 (CC1), R39.1
unnamed: J3.B5 (CC2), R38.1
unnamed: CR4.1, J4.4, R42.2
unnamed: CR3.1, J4.5, R41.2
unnamed: CR2.1, J4.6, R40.2
unnamed: R77.2, U4.42 (PA8)
unnamed: R78.2, U4.43 (PA9)
unnamed: R79.2, U4.44 (PA10)
unnamed: R80.2, U4.24 (PB0)
unnamed: R81.2, U4.25 (PB1)
unnamed: R69.1, U4.40 (PC8)
unnamed: R70.1, U4.41 (PC9)
unnamed: R82.1, U4.2 (PC13)
unnamed: C51.1, U4.3 (PC14), Y2.1
unnamed: C52.1, U4.4 (PC15), Y2.2
unnamed: C1.1, U4.5 (PF0), Y1.1
unnamed: R33.2, U4.6 (PF1)
Vref: C72.1, C73.1, C75.1, FB1.1, U4.28 (VREF+), U4.29 (VDDA); also elsewhere on the board

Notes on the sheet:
Power bypass Capacitors
TVS should be routed nearby the connectors
[3] STM32G431RBT6 Controller Interface
NRST circuit
For high speed I2C bus we can use smaller resistor 4K7 or 1K ohm
Debugger Interface (Serial Wire Debugger)
USB-C
Theses resistors should be closed to controller
This res adjust from 0 to 1K
This MCU can handle the FOC control Algorithme
one of 100nF should be placed near to VREF

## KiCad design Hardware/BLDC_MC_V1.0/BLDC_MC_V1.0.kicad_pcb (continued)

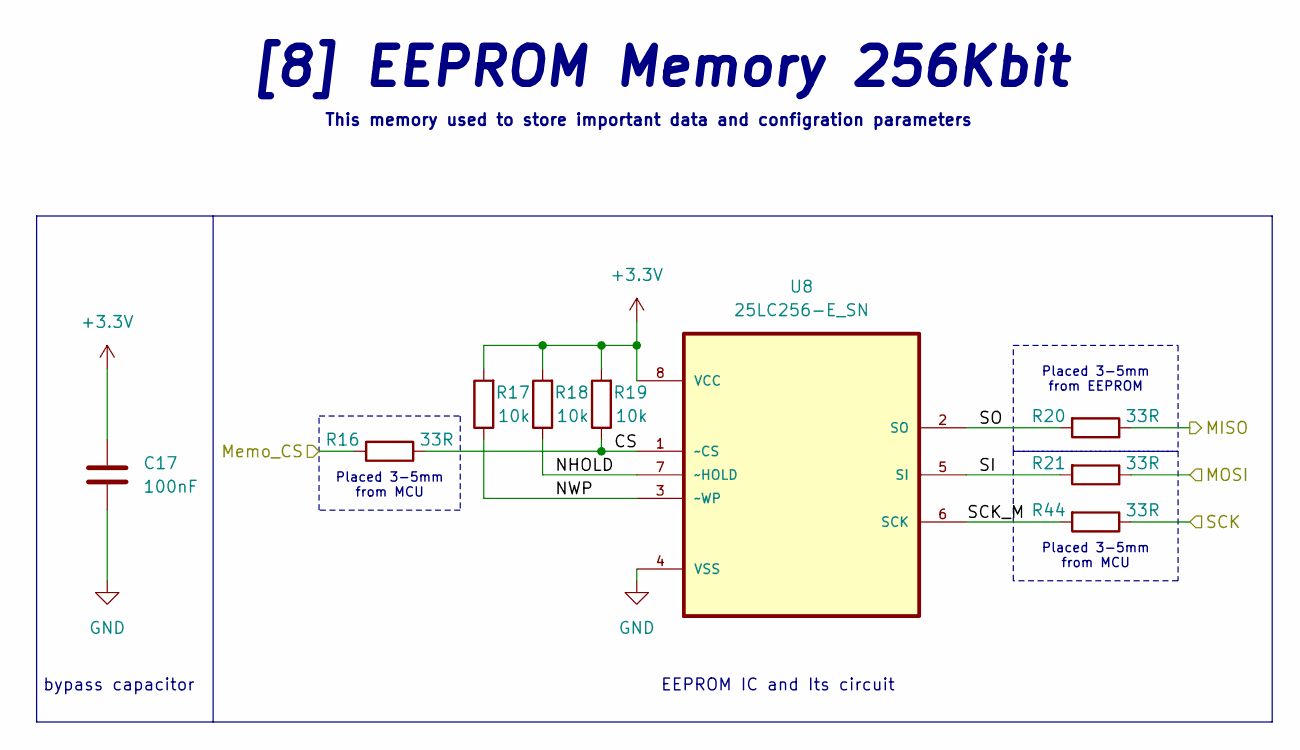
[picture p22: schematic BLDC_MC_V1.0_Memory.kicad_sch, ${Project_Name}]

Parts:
C17: 100nF; C_0805_2012Metric; LCSC_PN C28233
R16, R20, R21, R44: 33R; R_0603_1608Metric; LCSC_PN C108661
R17, R18, R19: 10k; R_0603_1608Metric; LCSC_PN C95204
U8: 25LC256-E_SN; SOIC127P599X175-8N; MPN 25LC256-E/SN; LCSC_PN C1349834

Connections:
+3.3V: C17.1, R17.2, R18.2, R19.2, U8.8 (VCC); also elsewhere on the board
/BLDC_MC_V1.0_MCU/MISO: R20.1; also elsewhere on the board
/BLDC_MC_V1.0_MCU/MOSI: R21.1; also elsewhere on the board
/BLDC_MC_V1.0_MCU/Memo_CS: R16.2; also elsewhere on the board
/BLDC_MC_V1.0_MCU/SCK: R44.1; also elsewhere on the board
/BLDC_MC_V1.0_Memory/CS: R16.1, R19.1, U8.1 (~CS)
/BLDC_MC_V1.0_Memory/NHOLD: R18.1, U8.7 (~HOLD)
/BLDC_MC_V1.0_Memory/NWP: R17.1, U8.3 (~WP)
/BLDC_MC_V1.0_Memory/SCK_M: R44.2, U8.6 (SCK)
/BLDC_MC_V1.0_Memory/SI: R21.2, U8.5 (SI)
/BLDC_MC_V1.0_Memory/SO: R20.2, U8.2 (SO)
GND: C17.2, U8.4 (VSS); also elsewhere on the board

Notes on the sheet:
Placed 3-5mm from EEPROM
Placed 3-5mm from MCU
EEPROM IC and Its circuit
This memory used to store important data and configration parameters
bypass capacitor
[8] EEPROM Memory 256Kbit

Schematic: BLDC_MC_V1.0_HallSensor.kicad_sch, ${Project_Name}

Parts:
C58, C59, C60: C; C_0603_1608Metric
C61, C62, C63: 100nF; C_0805_2012Metric; LCSC_PN C28233
R15, R49, R52: 10k; R_0603_1608Metric; LCSC_PN C95204
R45, R47, R50: 18K; R_0603_1608Metric; LCSC_PN C309650
R46, R48, R51: 30K; R_0603_1608Metric; LCSC_PN C723585
U3, U10, U11: TLV9061IDBVR; SOT95P280X145-5N; LCSC_PN C398358

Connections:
+3.3V: C61.1, C62.1, C63.1, U3.5 (V+), U10.5 (V+), U11.5 (V+); also elsewhere on the board
/BLDC_MC_V1.0_Connectors/Hall_A: R45.2; also elsewhere on the board
/BLDC_MC_V1.0_Connectors/Hall_B: R47.2; also elsewhere on the board
/BLDC_MC_V1.0_Connectors/Hall_C: R50.2; also elsewhere on the board
/BLDC_MC_V1.0_HallSensor/Hall_Phase_A: U3.1 (OUT), U3.4 (IN-); also elsewhere on the board
/BLDC_MC_V1.0_HallSensor/Hall_Phase_B: U10.1 (OUT), U10.4 (IN-); also elsewhere on the board
/BLDC_MC_V1.0_HallSensor/Hall_Phase_C: U11.1 (OUT), U11.4 (IN-); also elsewhere on the board
GND: C58.2, C59.2, C60.2, C61.2, C62.2, C63.2, R46.2, R48.2, R51.2, U3.2 (V-), U10.2 (V-), U11.2 (V-); also elsewhere on the board
unnamed: C58.1, R15.1, R45.1, R46.1
unnamed: C59.1, R47.1, R48.1, R49.1
unnamed: C60.1, R50.1, R51.1, R52.1
unnamed: R15.2, U3.3 (IN+)
unnamed: R49.2, U10.3 (IN+)
unnamed: R52.2, U11.3 (IN+)

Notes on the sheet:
For filtering the signal Limiting the input current
[6] Hall Effect Sensor Interface
+3.125V
Drop down the voltage from 5 to 3.3V
For the 3 Phases of Hall Sensor
Buffer OpAmp

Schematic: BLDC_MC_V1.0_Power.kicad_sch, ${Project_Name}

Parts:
C3, C4, C7, C8, C31, C35, C54, C89, C90: 100nF; C_0805_2012Metric; LCSC_PN C28233
C5, C6, C26, C27: 47uF; C_1206_3216Metric; LCSC_PN C403725
C9, C10, C29, C30: 47uF; CP_Elec_10x10.5; LCSC_PN C46528101
C14: 10nF; C_1206_3216Metric; LCSC_PN C377055
C28: 10pF; C_0603_1608Metric; LCSC_PN C1634
C32: 470nF; C_0805_2012Metric; LCSC_PN C13967
C33: 10nF; C_0603_1608Metric; LCSC_PN C100042
C34: 2.2uF; C_0603_1608Metric; LCSC_PN C415535
C36, C53: 1uF; C_0805_2012Metric; LCSC_PN C28323
C37, C55, C56: 4.7uF; C_1206_3216Metric; LCSC_PN C51205
CR10: SMDJ110CA; SMDJSeries_LTF; LCSC_PN C2990268
D1, D2, D3, D4: LED; LED_0603_1608Metric; LCSC_PN C19171390
H1, H2, H3, H4: MountingHole_Pad; MountingHole_2.2mm_M2_Pad_Via
L1: 10uH; L_KOHERelec_MDA7030; LCSC_PN C149584
NT4: NetTie_2; NetTie-2_SMD_Pad2.0mm
Q7: BSC027N10NS5ATMA1; PG-TSON-8-3_INF; PARTREV 2.1; LCSC_PN C534315
R1, R2: 100K; R_0603_1608Metric; LCSC_PN C122538
R3, R6: 0R; R_0603_1608Metric; LCSC_PN C2906974
R4: 9.09K; R_0603_1608Metric; LCSC_PN C844591
R5, R34, R37: 10k; R_0603_1608Metric; LCSC_PN C98220
R9: 1MR; R_1206_3216Metric; LCSC_PN C2907441
R35, R36: 3k3; R_0603_1608Metric; LCSC_PN C22978
U1: LM76005RNPR; QFN50P600X400X80-31N; PARTREV A; LCSC_PN TI LM76005RNPR
U5: LDL1117S33R; SOT230P700X180-4N; PARTREV 7; LCSC_PN C435835
U7: NCV4274ADT50RKG; DPAK-3_ONS; LCSC_PN C233416
U16: LM74700QDRQ1; SOIC8_D_TEX; LCSC_PN C33579657

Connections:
+3.3V: C35.1, C37.1, R36.1, U5.2 (VOUT), U5.4 (VOUT); also elsewhere on the board
+5V: C55.1, C56.1, R35.1, U7.3 (Q); also elsewhere on the board
+12V: C3.1, C4.1, C5.2, C6.2, C26.2, C27.2, C28.1, C36.1, C53.1, C54.1, L1.2, R2.1, R5.2, R6.2, R34.1, U5.3 (VIN), U7.1 (I); also elsewhere on the board
/BLDC_MC_V1.0_Connectors/Vin_DC: C89.1, C90.1, CR10.1, Q7.5, Q7.6, Q7.7, Q7.8, U16.2 (EN), U16.5 (ANODE); also elsewhere on the board
/BLDC_MC_V1.0_Power/Buck_SW: C32.1, L1.1, U1.1 (SW), U1.2 (SW), U1.3 (SW), U1.4 (SW), U1.5 (SW)
/BLDC_MC_V1.0_Power/VCC_Buck: C34.1, U1.8 (VCC)
/BLDC_MC_V1.0_Power/chassis_ground: C14.1, H1.1 (1_1), H2.1 (1_1), H3.1 (1_1), H4.1 (1_1), R9.1
AGND: C31.2, C33.2, C34.2, NT4.2, R1.2, R3.2, R4.2, U1.13 (AGND), U1.14 (AGND), U1.15 (AGND), U1.19 (NC), U1.27 (NC), U1.28 (NC), U1.29 (NC), U1.30 (NC)
GND: C3.2, C4.2, C5.1, C6.1, C7.2, C8.2, C9.2, C10.2, C14.2, C26.1, C27.1, C29.2, C30.2, C35.2, C36.2, C37.2, C53.2, C54.2, C55.2, C56.2, C90.2, CR10.2, D1.1 (K), D2.1 (K), D3.1 (K), D4.1 (K), NT4.1, R9.2, U1.24 (GND), U1.25 (GND), U1.26 (GND), U1.31 (EP), U5.1 (GND), U7.2 (GND), U16.1 (GND); also elsewhere on the board
unnamed: D1.2 (A), R37.2
unnamed: D2.2 (A), R34.2
unnamed: D3.2 (A), R35.2
unnamed: D4.2 (A), R36.2
unnamed: C31.1, R6.1, U1.9 (BIAS)
unnamed: C32.2, U1.6 (BOOT)
unnamed: C28.2, R2.2, R4.1, U1.12 (FB)
unnamed: R5.1, U1.16 (PGOOD)
unnamed: R1.1, U1.10 (RT)
unnamed: C33.1, U1.11 (SS/TRK)
unnamed: R3.1, U1.17 (SYNC/MODE)
unnamed: Q7.4, U16.6 (GATE)
unnamed: U16.3 (N.C), U16.7 (N.C)
unnamed: C89.2, U16.4 (VCAP)
Vin: C7.1, C8.1, C9.1, C10.1, C29.1, C30.1, Q7.1, Q7.2, Q7.3, R37.1, U1.18 (EN), U1.20 (PVIN), U1.21 (PVIN), U1.22 (PVIN), U16.8 (CATHODE); also elsewhere on the board

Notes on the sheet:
Input Cap Bank
Output Cap Bank
The maximum input votage of this 60V so we can use for BLDC motors up to 60V
LDO Fixed out 5V
Indication Leds
Buck IC Circuit
input Capacitor Bank To make the input power pure DC
LDO Fixed out 3.3V
Input PWR Protection
Replaced by 0R
[2] Power Conversion Vin to 12V and 5V to 3.3V
Output Capacitor Bank Recommended from IC datasheet Cout = 150uf Referance design puts 5 of 47uf

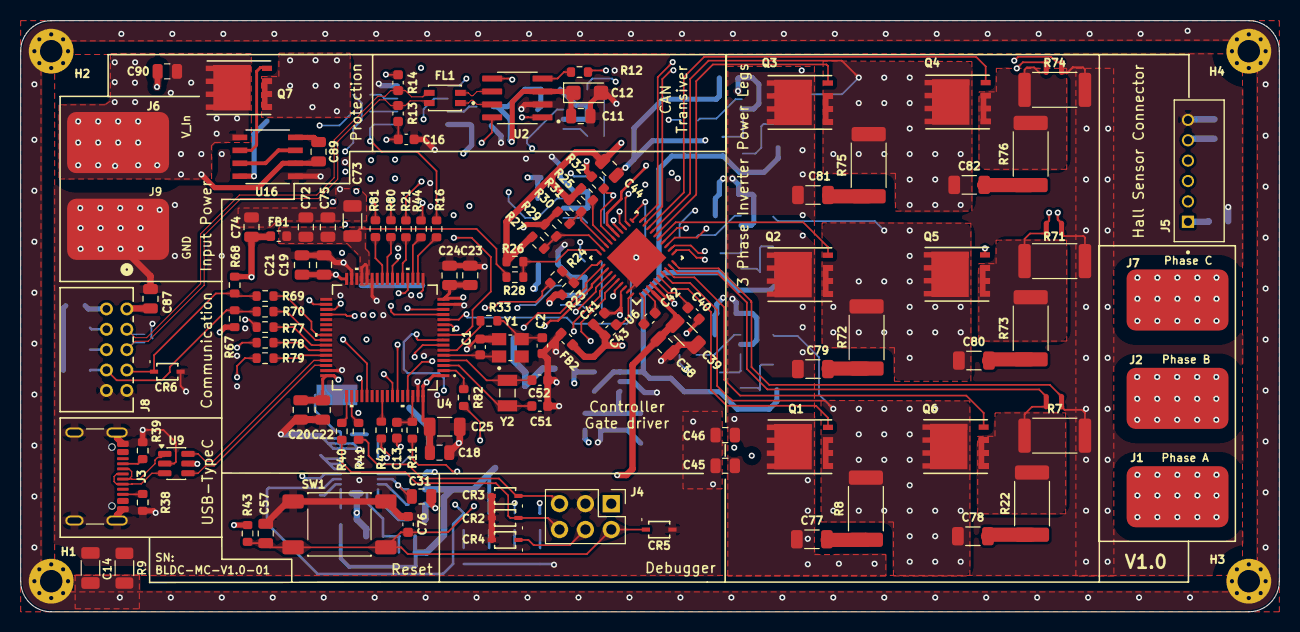
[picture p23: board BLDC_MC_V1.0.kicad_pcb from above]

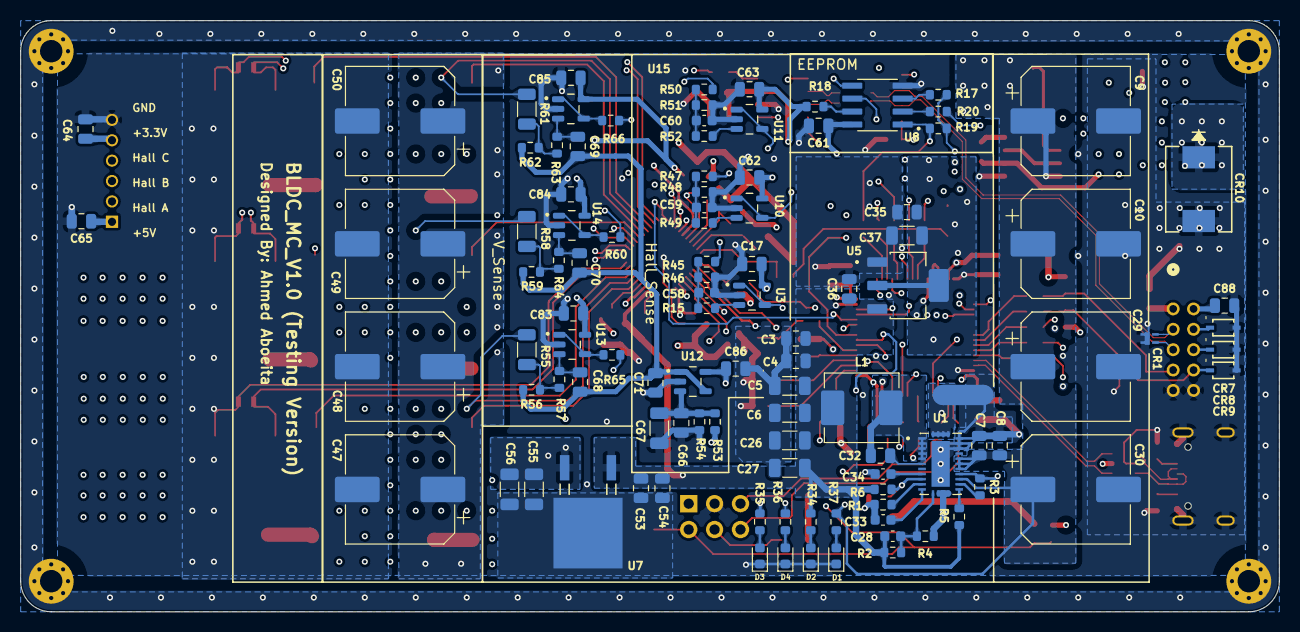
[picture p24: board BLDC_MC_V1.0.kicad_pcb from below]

Board: 8 copper layers, 123.5 x 58.0 mm, 234 parts (106 on the bottom side), 148 nets.

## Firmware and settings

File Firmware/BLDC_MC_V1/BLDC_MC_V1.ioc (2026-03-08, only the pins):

Mcu.UserName=STM32G431RBTx
PA0.Signal=ADC1_IN1
PA1.Signal=ADC1_IN2
PA10.Signal=S_TIM1_CH3
PA11.Signal=USB_DM
PA12.Signal=USB_DP
PA13.Signal=SYS_JTMS-SWDIO
PA14.Signal=SYS_JTCK-SWCLK
PA2.Signal=ADC1_IN3
PA3.Signal=ADC1_IN4
PA4.Signal=GPIO_Output
PA5.Signal=SPI1_SCK
PA6.Signal=SPI1_MISO
PA7.Signal=SPI1_MOSI
PA8.Signal=S_TIM1_CH1
PA9.Signal=S_TIM1_CH2
PB0.Signal=TIM1_CH2N
PB1.Signal=TIM1_CH3N
PB12.Signal=GPIO_Output
PB13.Signal=GPIO_Input
PB14.Signal=ADC1_IN5
PB3.Signal=SYS_JTDO-SWO
PB5.Signal=GPIO_Output
PB6.Signal=GPIO_Output
PB7.Signal=SYS_PVD_IN
PB8-BOOT0.Signal=FDCAN1_RX
PB9.Signal=FDCAN1_TX
PC0.Signal=ADC1_IN6
PC1.Signal=ADC1_IN7
PC10.Signal=UART4_TX
PC11.Signal=UART4_RX
PC13.Signal=TIM1_CH1N
PC14-OSC32_IN.Signal=RCC_OSC32_IN
PC15-OSC32_OUT.Signal=RCC_OSC32_OUT
PC2.Signal=ADC1_IN8
PC5.Signal=ADC2_IN11
PC8.Signal=I2C3_SCL
PC9.Signal=I2C3_SDA
PF0-OSC_IN.Signal=RCC_OSC_IN
PF1-OSC_OUT.Signal=RCC_OSC_OUT

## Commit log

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2026-01-03 Add buck converter IC 36V input to 3.3V
    [BLDC_Motor_Driver.kicad_sch, CAN_Transceiver.kicad_sch, Power_Sheet.kicad_sch]
2026-01-04 started the MCU and Finializing the MCU the next step will be the DRV
    [MCU.kicad_sch]
2026-01-05 Add Selection of CAN IC and arrange the sheet of buck converter
    [BLDC_Motor_Driver.kicad_sch, CAN_Transceiver.kicad_sch, MCU.kicad_sch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]
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2026-01-07 Edit the value of series resistor to 33R instead of 49.9R
    [CAN_Transceiver.kicad_sch]
2026-01-07 Add the EEPROM memory sheet and finish the circuit of it
    [BLDC_Motor_Driver.kicad_sch, Memory.kicad_sch]
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2026-01-07 Add the MOSFET for the 3 phase inverter sheet
    [3Phase_Inverter_legs.kicad_sch, BLDC_Motor_Driver.kicad_sch]
2026-01-09 Rename the project files to take version name
    [3Phase_Inverter_legs.kicad_sch, BLDC_MC_V1.0.kicad_pcb, BLDC_MC_V1.0.kicad_sch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]
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2026-01-10 add the new edits to Buck converter sheet and edit other sheets name
    [BLDC_MC_V1.0_CAN_Transceiver.kicad_sch, BLDC_MC_V1.0_MCU.kicad_sch, BLDC_MC_V1.0_Memory.kicad_sch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]
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2026-01-12 Add datasheet and library of DVR (gate drive IC) and add the sheet of gate drive circuit
    [BLDC_MC_V1.0.kicad_sch, BLDC_MC_V1.0_Gate_Drive.kicad_sch]
2026-01-25 Edit the connection between sheets and add some details and connections to gatedrive sheet
    [BLDC_MC_V1.0.kicad_sch, BLDC_MC_V1.0_3Phase_Inverter_legs.kicad_sch, BLDC_MC_V1.0_CAN_Transceiver.kicad_sch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]
2026-02-02 Restore the importenat project files from last commit and define the routing of current sensor as differntial pair
    [BLDC_MC_V1.0.kicad_sch, BLDC_MC_V1.0_3Phase_Inverter_legs.kicad_sch, BLDC_MC_V1.0_Gate_Drive.kicad_sch]
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2026-02-08 Edit Controller sheet and add oscillators for the controller
    [BLDC_MC_V1.0.kicad_sch, BLDC_MC_V1.0_CAN_Transceiver.kicad_sch, BLDC_MC_V1.0_MCU.kicad_sch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]
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2026-02-13 Edit the ground of the capacitors to PGND
    [BLDC_MC_V1.0_3Phase_Inverter_legs.kicad_sch]
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2026-02-13 Edit FW project using external oscillator and confg of PWM
    [BLDC_MC_V1.ioc]
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2026-02-21 Add the USB-C connector - define the PWM pins and other enable and fault pins for gate driver
    [BLDC_MC_V1.0.kicad_sch, BLDC_MC_V1.0_MCU.kicad_sch, BLDC_MC_V1.0_Power.kicad_sch]
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2026-03-01 Add TVS for NRST and add pushbutton for rest
    [BLDC_MC_V1.0_MCU.kicad_sch]
2026-03-02 Add the new bipolar TVS for the debugger connector
    [BLDC_MC_V1.0_MCU.kicad_sch]
2026-03-04 Add hall sensor sheet and its simulation file
    [BLDC_MC_V1.0.kicad_sch, BLDC_MC_V1.0_Memory.kicad_sch, untitled.kicad_sch]
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2026-03-04 Edit the sch of the project by adding the hall sensor sheet and interface with the MCU sheet and annotate the components in memory sheet
    [BLDC_MC_V1.0.kicad_sch, BLDC_MC_V1.0_HallSensor.kicad_sch, BLDC_MC_V1.0_MCU.kicad_sch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]
2026-03-06 Add voltage sensor to measure the 3 phase voltage of inverter bridge
    [BLDC_MC_V1.0.kicad_sch, BLDC_MC_V1.0_HallSensor.kicad_sch, BLDC_MC_V1.0_MCU.kicad_sch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]
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2026-03-08 Add the snubber circuit and arrange the sheet
    [BLDC_MC_V1.0_3Phase_Inverter_legs.kicad_sch]
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2026-03-08 Add space in the power sheet for input power ( reverce polarity and over current protection )
    [BLDC_MC_V1.0_Power.kicad_sch]
2026-03-08 Edit the voltage sensor sheet by adding low pass filter
    [BLDC_MC_V1.0_Voltage_Sensor.kicad_sch]
2026-03-08 Edit the controller sheet and CAN sheet to adjust the interface between them
    [BLDC_MC_V1.0.kicad_sch, BLDC_MC_V1.0_CAN_Transceiver.kicad_sch, BLDC_MC_V1.0_MCU.kicad_sch]
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2026-03-14 Add the connectors used in the project ( power, sensor and communication connectors)
    [BLDC_MC_V1.0_Connectors.kicad_sch]
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2026-03-20 Add in series resistors for PWM pins and Test points for the same pins
    [BLDC_MC_V1.0_MCU.kicad_sch]
2026-03-20 Add test points for the gate drive pins
    [BLDC_MC_V1.0_Gate_Drive.kicad_sch]
2026-03-22 Solve all errors and wornings in project
    [BLDC_MC_V1.0.kicad_pcb, BLDC_MC_V1.0.kicad_sch, BLDC_MC_V1.0_3Phase_Inverter_legs.kicad_sch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]
2026-03-28 Add notes about how to adjust the snubber circuit
    [BLDC_MC_V1.0_3Phase_Inverter_legs.kicad_sch]
2026-03-28 Run DRC and solve all errors and warnings (project updated to Kicad 10)
    [BLDC_MC_V1.0.kicad_pcb, BLDC_MC_V1.0.kicad_sch, BLDC_MC_V1.0_CAN_Transceiver.kicad_sch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]
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2026-06-28 Add Stackup for the PCB and define the control impedance traces
    [BLDC_MC_V1.0.kicad_pcb]
2026-06-29 Routing Power plans and change the power connedtors
    [BLDC_MC_V1.0.kicad_pcb, BLDC_MC_V1.0_3Phase_Inverter_legs.kicad_sch, BLDC_MC_V1.0_Connectors.kicad_sch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]
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2026-07-07 Routing input voltage and add vias for power pads
    [BLDC_MC_V1.0.kicad_pcb]
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2026-07-26 Routing the power connections and some GD signals
    [BLDC_MC_V1.0.kicad_pcb, BLDC_MC_V1.0_3Phase_Inverter_legs.kicad_sch, BLDC_MC_V1.0_Gate_Drive.kicad_sch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]
2026-07-30 Update the layout and routing of the board by connecting some of the gate driver traces
    [BLDC_MC_V1.0.kicad_pcb]
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2026-08-01 Update the layout of the board by routing the connections between controller and gate drive
    [BLDC_MC_V1.0.kicad_pcb, BLDC_MC_V1.0_3Phase_Inverter_legs.kicad_sch, BLDC_MC_V1.0_Gate_Drive.kicad_sch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]
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2026-08-15 Solve most of ERC errors
    [BLDC_MC_V1.0.kicad_pcb, BLDC_MC_V1.0_MCU.kicad_sch]
2026-08-16 Solved all the DRC errors
    [BLDC_MC_V1.0.kicad_pcb]
2026-08-16 Solved all the worrnings founded
    [BLDC_MC_V1.0.kicad_pcb, BLDC_MC_V1.0_MCU.kicad_sch]
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2026-08-18 Updated the layout by adding more vias for Vin plan
    [BLDC_MC_V1.0.kicad_pcb]
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2026-08-19 Added Fabrication_Files after checked it with JLCPCB website
    [BLDC_MC_V1.0-B_Adhesive.gbr, BLDC_MC_V1.0-B_Courtyard.gbr, BLDC_MC_V1.0-B_Mask.gbr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]
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2026-08-20 Update the title box of the sch sheets
    [BLDC_MC_V1.0.kicad_sch, BLDC_MC_V1.0_3Phase_Inverter_legs.kicad_sch, BLDC_MC_V1.0_CAN_Transceiver.kicad_sch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]
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
